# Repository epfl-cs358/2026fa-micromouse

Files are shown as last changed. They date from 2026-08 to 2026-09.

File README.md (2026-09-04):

# Fall 2026 CS-358 Individual Project: a Micromouse 🐭

<!--<p align="center"><img src="https://github.com/user-attachments/assets/d70ca096-ef3c-48a5-9e2c-f239ba1cced6" width=700></p>-->

<!--<p align="center"><img src="https://github.com/user-attachments/assets/1fc31847-2d3d-4c5c-aa62-841a447577e7" width=600></p>-->



## Project overview

This semester project focuses on micromice which are small autonomous robotic "mice" designed to solve a maze as quickly as possible. As seen in [various videos](https://youtu.be/ZMQbHMgK2rw?si=J3iyXzNXOJgDFyq4), these robots can navigate and complete a maze in just a few seconds, demonstrating remarkable speed and precision.
<p align="center"><br><sub>Source: The Fastest Maze-Solving Competition On Earth<br><a>https://youtu.be/ZMQbHMgK2rw?si=60H5i8q6jv-QUGHG</a></sub></p>

Just like these spectacular micromice, we are going to build a little micromouse that uses sensors, motors, and a microcontroller. However, instead of solving mazes at a high speed, this project focuses on a different but equally interesting robotics challenge: **obstacle avoidance**, similar to a robotic vacuum cleaner. (Full maze solving is a bit involved for the individual project.)

You will build a small mobile robot capable of navigating an unknown environment, avoiding obstacles, much like a simplified Roomba. Below are some photos of the Micromouse you will build. (Note that those photos are from a more advanced version with three sensors and a Gyro)

<p float="left">
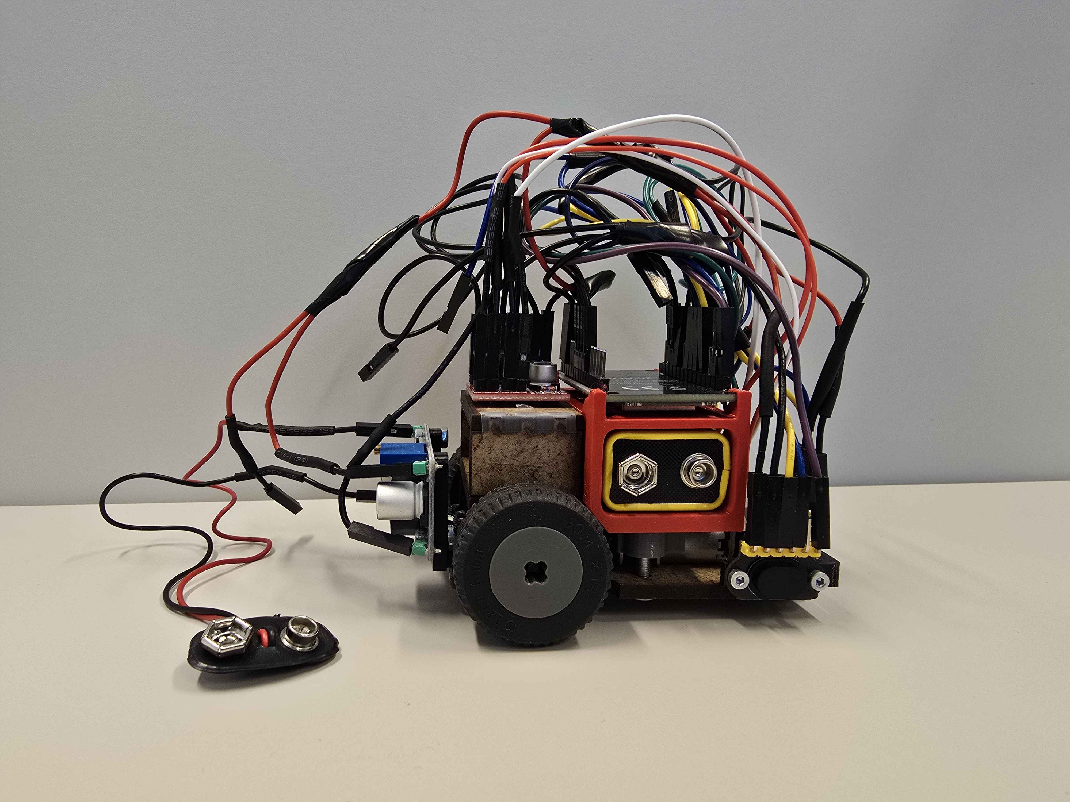
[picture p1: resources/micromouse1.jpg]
	
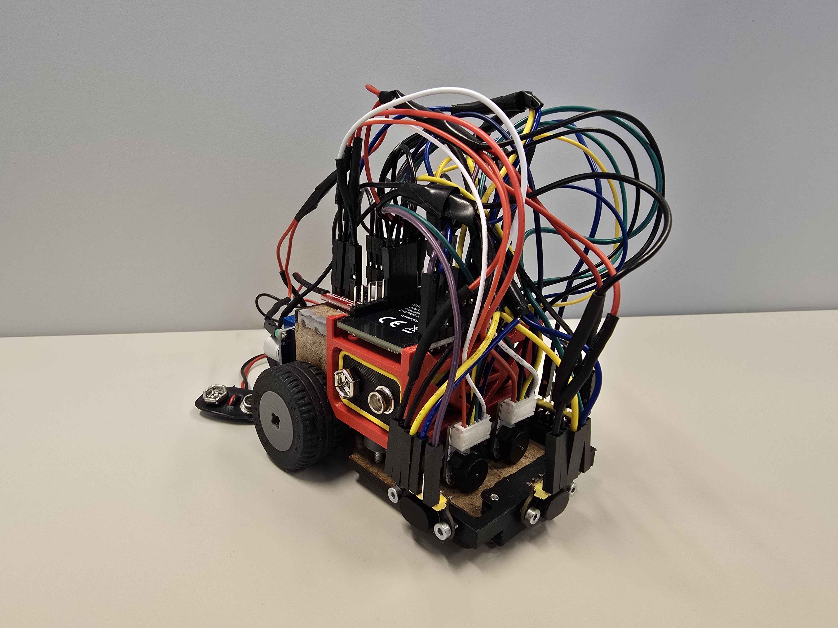
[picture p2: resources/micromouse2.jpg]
	
</p>  
<p float="left">
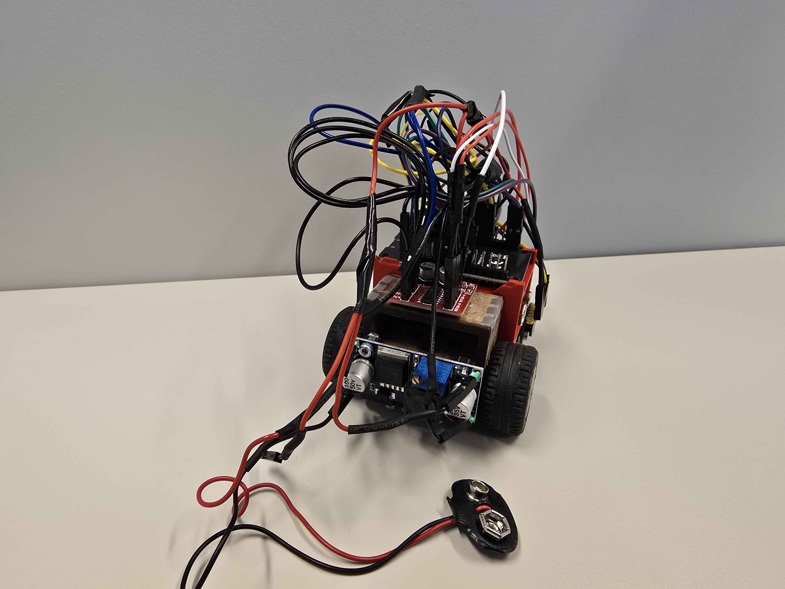
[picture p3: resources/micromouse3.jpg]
	
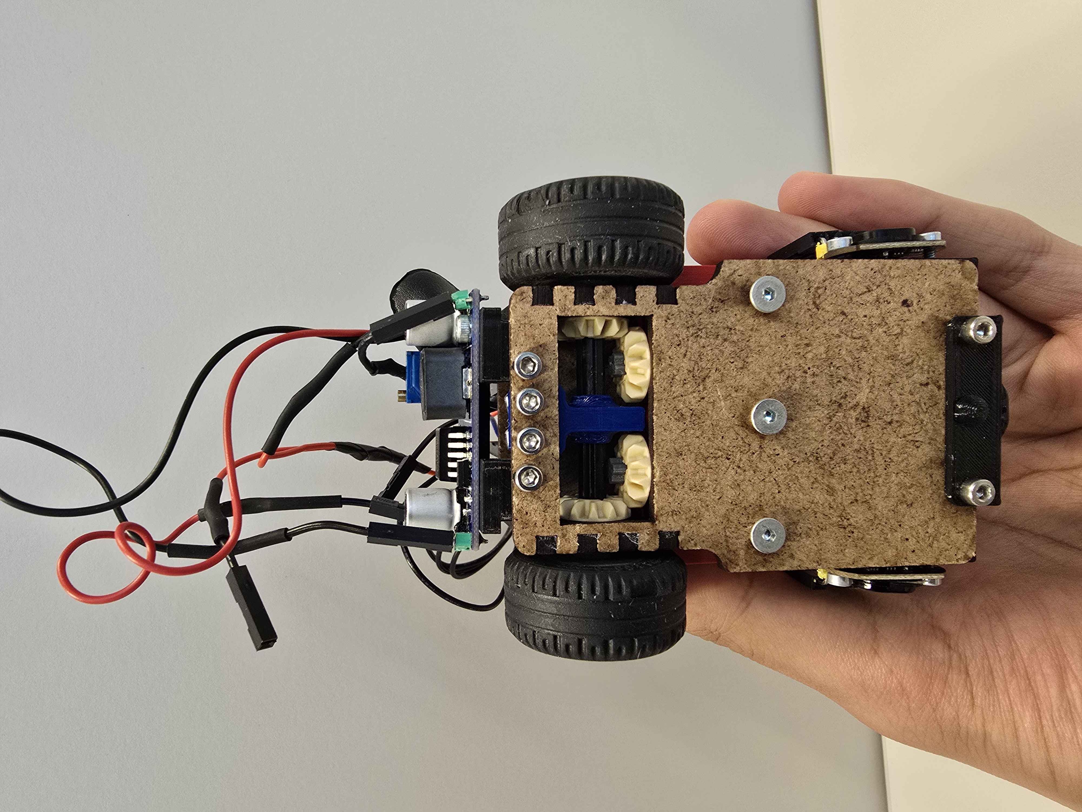
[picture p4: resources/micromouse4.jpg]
	
</p>  

The aim of this project is to get hands-on experience in a number of areas. We'll be learning how to assemble components following a circuit, soldering, 3D design, laser-cutting and programming micro-controllers.

⚠️ **An important note**: For this project, you can use either *Arduino IDE* or *PlatformIO*. Arduino IDE is a very basic IDE and also supports ESP32 development. However, please note that the time required to upload code to the ESP32 is high (on the order of one minute).

Another option is to use PlatformIO: a famous VSCode extension for programming microcontrollers, including ESP32s. Upload times are considerably faster with PlatformIO. In addition, familiarizing yourself with PlatformIO can be useful for other projects using ESP32s, Arduino and many other microcontrollers.

Whatever your choice, you'll find a tutorial for importing the project and installing the necessary libraries on Arduino IDE and PlatformIO in the [Software](#software) section

<!--⚠️ Please consider consulting the project proposal for more details about MinosMouse :memo:[Project proposal](https://github.com/epfl-cs358/2024fa-minosmouse/blob/cbe9dc045ea7b2e5f2d51d4c105a9bb93ee3844e/Proposal/MIT___MicroMouse.pdf):memo:-->

## Micromouse design

The micromouse is 95x58mm.

In order to achieve precise movement, the micromouse makes extensive use of control theory, more specifically PID systems. Thanks to this, the micromouse can correct itself in real time using its various sensors. 

### Hardware Overview

The micromouse consists of the following components:

- 2x N20 Motors 500RPM
- 1x Motor Driver MX1508
- 1x Time-Of-Flight sensors ToF400C-VL53L1X
- 1x Microcontroller ESP32 30pin
- 1x 9V battery
- 1x Buck converter LM2596
- 1x 9V battery connector
- 2x Lego axels 4L
- 2x Lego tires
- 4x Lego gears

⚠️ Check that no parts are missing before starting the project !

 Encoders keep track of how many steps each motor has taken. This is important because, unlike stepper motors, the brushed motors we're using for this project (N20 gear motors) are not exactly the same. In fact, these motors will always have a small difference in speed between them, and we need to compensate for this difference (however slight!) so that the micromouse can move straight forward / make precise movements. Thanks to the encoders, we can compensate for the difference in speed between the two motors by reading the number of steps each motor has taken, and trying to keep this number of steps almost equal.

## Tasks

### Overview

The goal of this semester is to work close to the hardware of the mouse, you'll have to build the mouse and code the interface with the sensors and motors. The expected behavior will be to drive up to an obstacle with a nice and straight tragectory, detect it, turn away and drive away. 

### 1 Hardware

 Build the mouse based on the instructions located further below in this document.

### 2 Design your 3D-printed wheels

To practice 3D design, you will design the wheels of the micromouse (not the tires).

The dimensions of the wheels are for you to choose, but beware: The behavior of the mouse depends heavily on these parameters!

Also, since we use lego shafts to attach the wheels to the gear box, you need to make sure, when designing the wheels, that the shaft fits in the wheel. For your information, here are the lego shaft dimensions:

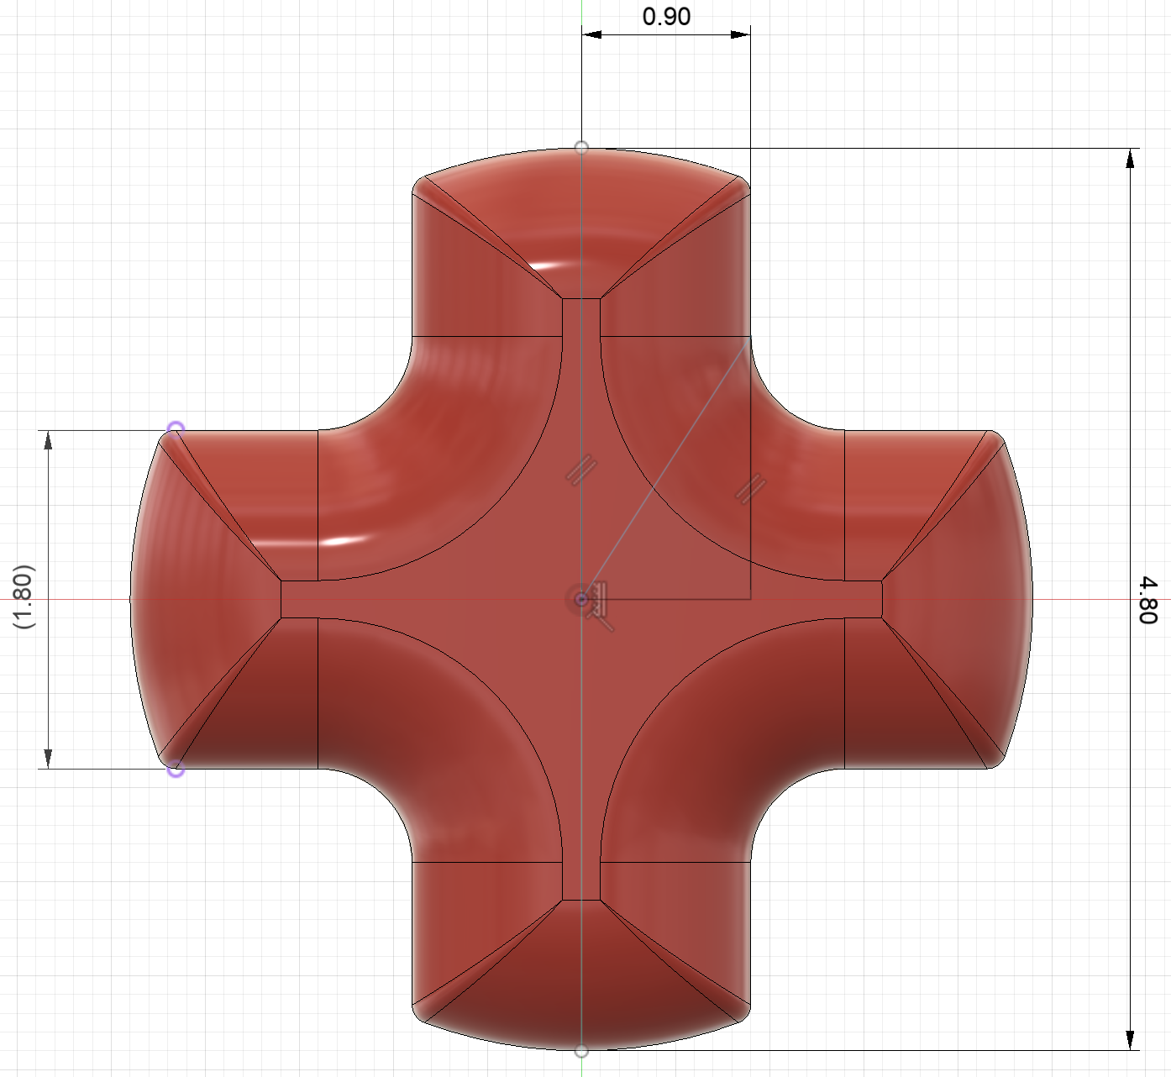
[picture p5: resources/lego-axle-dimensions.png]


For your reference, here is an example of a wheel that you may get inspired from. The tire is given to you and fits snuggly around a 17.7mm rim. The design given uses supports inside the rail that are a pain to remove, it's your job to find a better design if you want to avoid this issue :D

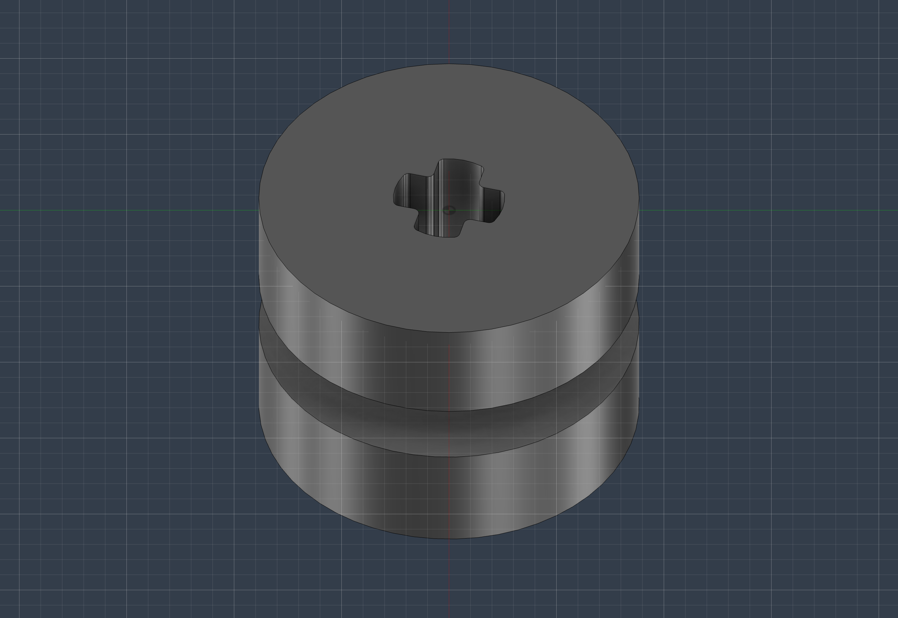
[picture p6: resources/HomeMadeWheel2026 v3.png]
  
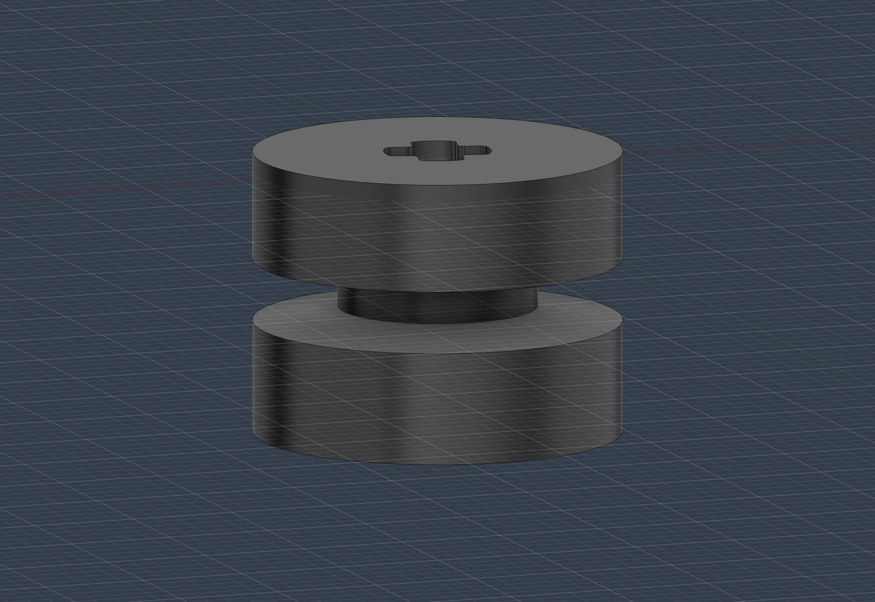
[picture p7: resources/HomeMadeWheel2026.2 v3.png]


This is the opportunity to make your product stand out! Fortunately this part is quite small and is therefore quite cheap and quick to manufacture, so don't be afraid to experiment!

### 3 Software Tasks

Your software tasks are divided into several categories:

#### Implement source files from provided interfaces

You will be given `.h` header files containing function signatures. Your task is to implement the corresponding `.cpp` files so that the functions exhibit the expected behavior.

- `encoders.h`  
  Functions related to encoder usage and measurements.

- `ToF.h`  
  Functions related to the front Time-of-Flight (ToF) sensor. You will need to calibrate your sensors to have accurate readings, this can be achieved with a simple linear regression.

- `motors.h`  
  Functions defining the API used to control the motors.  
  We have provided a few function signatures that we consider important, but this is not intended to be exhaustive. You are encouraged to extend the API with any additional functions you find useful. Make it your own.
  - Active braking

    Active braking is a technique used to stop a DC motor more quickly than simply cutting power.  
    With brushed DC motors, one common method is to short the motor terminals together. While the motor is still spinning, it acts like a generator and produces a voltage known as *back EMF* (electromotive force). By shorting the terminals, this generated current flows through the motor itself, creating a torque that opposes the rotation and rapidly slows the motor down.

    With brushed DC motors, this is commonly achieved by briefly shorting the motor terminals together (aka set both pins to High)

#### Design and implement algorithms independently

For these tasks, no file structure or function signatures will be provided. You are expected to design the software architecture and implementation yourself.

#### - Motor PID control

Implement a PID controller that adjusts the power delivered to each motor so both wheels rotate at the same speed. The objective is to improve the robot’s ability to drive in a straight line. 

A PID (*Proportional–Integral–Derivative*) controller is a feedback control algorithm commonly used in robotics and automation. It continuously measures the error between a target value and the current measured value, then adjusts the system output to minimize that error over time. You are expected to research how PID control works and tune your controller appropriately.

#### - Simple obstacle avoidance behavior

Implement an algorithm that:

1. Drives the robot forward in a straight line  
2. Detects an obstacle ahead  
3. Uses active braking and correction to stop approximately 5 cm from the wall  
4. Performs a ~140 degree turn in either direction to face away from the obstacle (you will not be graded on the accurracy of that turn)
5. Continues driving forward afterward

## Getting started: Making the micromouse

### Assembly

⚠️ At all times during the assembly process, refer to this document or to the provided `.step` file in order to avoid mistakes.

1. First things first, you need to laser-cut and 3D-print the parts of the micromouse. You can find the CAD of the parts to be laser-cut and 3D-printed in the project repository.

	You need to laser-cut the following parts:
    - 1x Base plate
    - 2x Side walls
	- 1x Top module plate

	You need to use **3mm** MDF: A sturdy enough width without being exceedingly heavy.

	You also need to 3D-print the following parts:
    - 2x N20-to-LEGO adapters
   	- 1x Motor bracket
   	- 1x Sensors holder
	- 1x Battery holder
   	- 1x Shaft holder
   	- 1x Backplate (Buck converter holder)

	⚠️ Most 3D parts were designed to require minimal to no supports. Be sure to disable them in PrusaSlicer when not necessary and mind the orientation of the parts when scheduling a print.

	### Useful PrusaSlicer Extras
  
	⚠️ If you want to specify which side of your part you want supported you can do that by using the **brush** tool. 
	

	⚠️Also, if you want the supports to be easily removable, you can use the **organic** supports option (although the sensor holder is the only piece that requires supports).
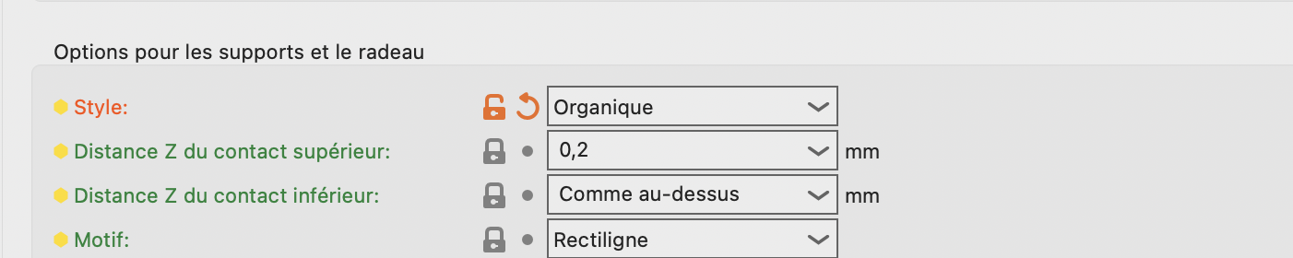
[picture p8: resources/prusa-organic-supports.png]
	

2. Once you have laser-cut parts, you can assemble them:

	⚠️ Be patient and careful when assembling MDF parts as they are fragile

	1. Put the shaft holder in the middle of the gearbox and scew it to the base plate.
	2. Wedge the top module plate on top of the two side plates.
	3. Wedge the aforementioned assembly into the base plate, you should feel some resistance.

💭 You should use **wood glue** to make everything secure but you will not be able to disassemble your mouse afterwards should you need to debug. Only do this if you are sure that you don't want to disassemble the parts.

3. Now, we install the motors on the micromouse:
    1. Put the N20-to-LEGO adapters on the motors
    2. Press the N20 Motors into the motor bracket. It should be a snug fit
	3. Insert nuts in the battery holder. Place the battery holder on top of the motor bracket and the Screw both of them to the chassi. Screws should be inserted from the bottom of the chassis.

	⚠️ Make sure the Lego adapter tips are properly aligned. The mouse would suffer from a lot of friction otherwise !
   
4. Mounting the gear box:
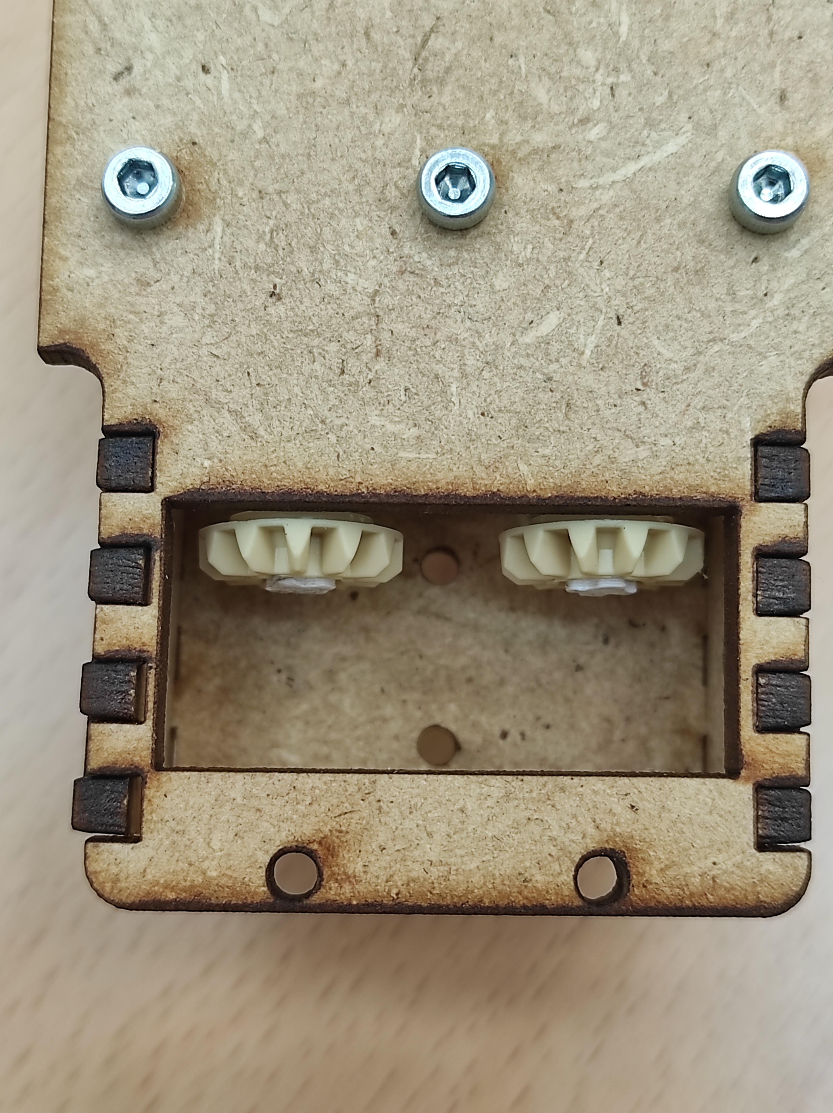
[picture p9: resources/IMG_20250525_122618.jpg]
	1. Install a gear on each of the N20-to-LEGO adapters. 
	2. Insert the lego shafts into the gearbox from the small hole in the gearbox walls. At the same time, add the other gear on the shaft and push it against the gearbox wall. The shafts should be maintained in place by the shaft holder which is in the middle of the gearbox.
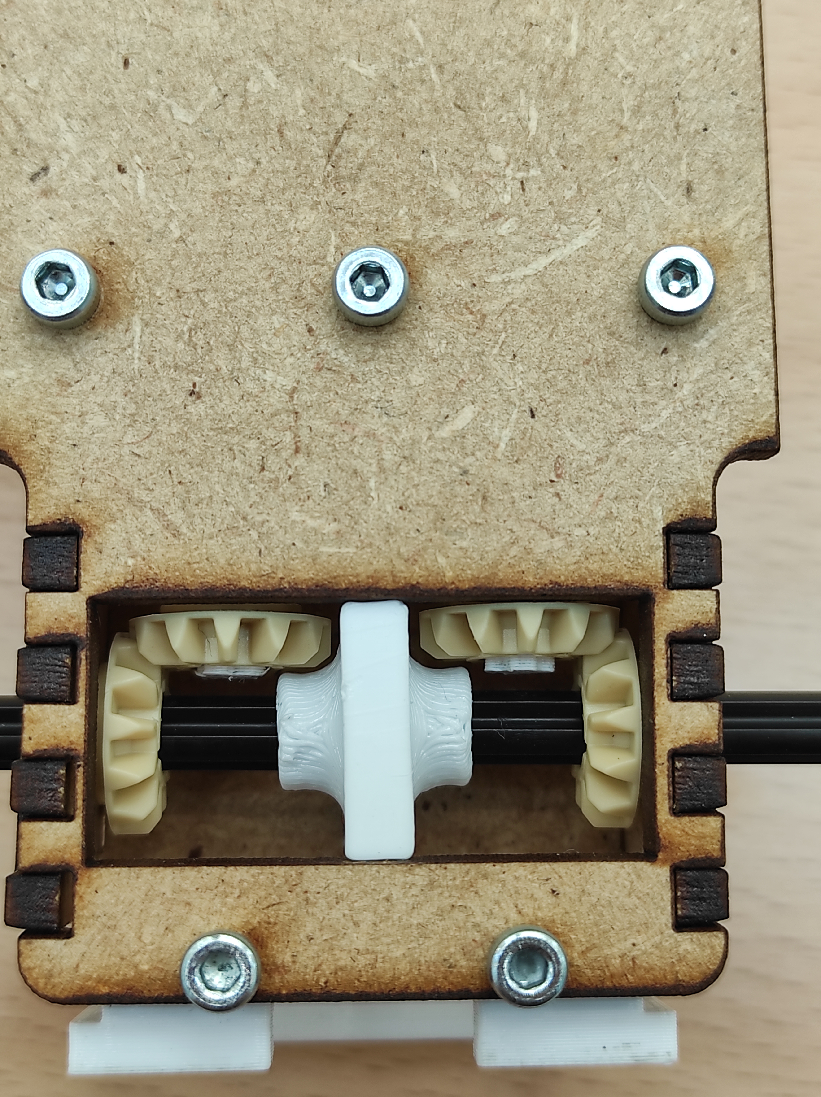
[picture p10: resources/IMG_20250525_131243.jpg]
	

5. Install the sensor holder on the front of the chassis. The sensor holder is designed to hold the 3 ToF sensors.

6. Finally, install the backplate on the back of the chassis by screwing it to the chassis. Same for the sensors holder: Attach it to the front of the chassis and screw it.

✅ After these steps, the basic mechanism of your mouse should be complete!

### Soldering
#### General Advice 
For this project, we recommend avoiding soldering wires directly to the boards. Instead, solder male header pins to the boards and create female cable assemblies to connect them.

When soldering male header pins to boards, make sure everything is stable and will not slip or move while you are heating the board and pins with the soldering iron. When soldering straight pins, you can use a breadboard to stabilize both the board and the pins (there is no need to push the pins too far into the breadboard). Make sure you adequately heat both the board and the pin before applying solder. The solder should not bead up, as that means the joint is too cold. Instead, it should flow smoothly around the metal ring and the pin, allowing you to add solder until you are satisfied with the amount.

We also recommend using appropriately sized solder wire for the task. For example, thinner solder wire makes it easier to control the amount of solder when working with the TOF sensor pins. The correct amount of solder should form an even, slightly convex “volcano” shape around the pin.

When soldering cable assemblies, make sure the stripped wires are twisted together securely. The wires should not pull apart easily once twisted together, the solder is intended primarily for electrical connectivity, not tensile strength. Try to find a good balance for the stripped wire length: if it is too long, it will require more solder and make it harder to achieve an even spread; if it is too short, twisting the wires together will be more difficult.

As with board soldering, make sure your setup is stable and that the wires are heated adequately before applying solder. Do not keep applying solder if it beads up, as this indicates the joint is not hot enough, remove the solder and continue heating.

A properly tinned soldering iron tip should look smooth, shiny, and evenly coated with a thin layer of solder. A dry, dark, or oxidized tip will not transfer heat effectively and will make soldering much more difficult. Regularly wipe the tip on the provided steel wool or brass wool cleaner and reapply a small amount of solder to keep it tinned between joints. If you have a stubborn black spot on the tip, you can use the acid paste to help remove the oxidation, then reapply solder to the tip and wipe it clean with the steel wool.
⚠️ Acid paste should be used sparingly as it can shorten the life span of the iron.

#### Schematics

The next step is to solder all the components together. This step needs to be done carefully as there is a lot of wires to solder in a small space.  

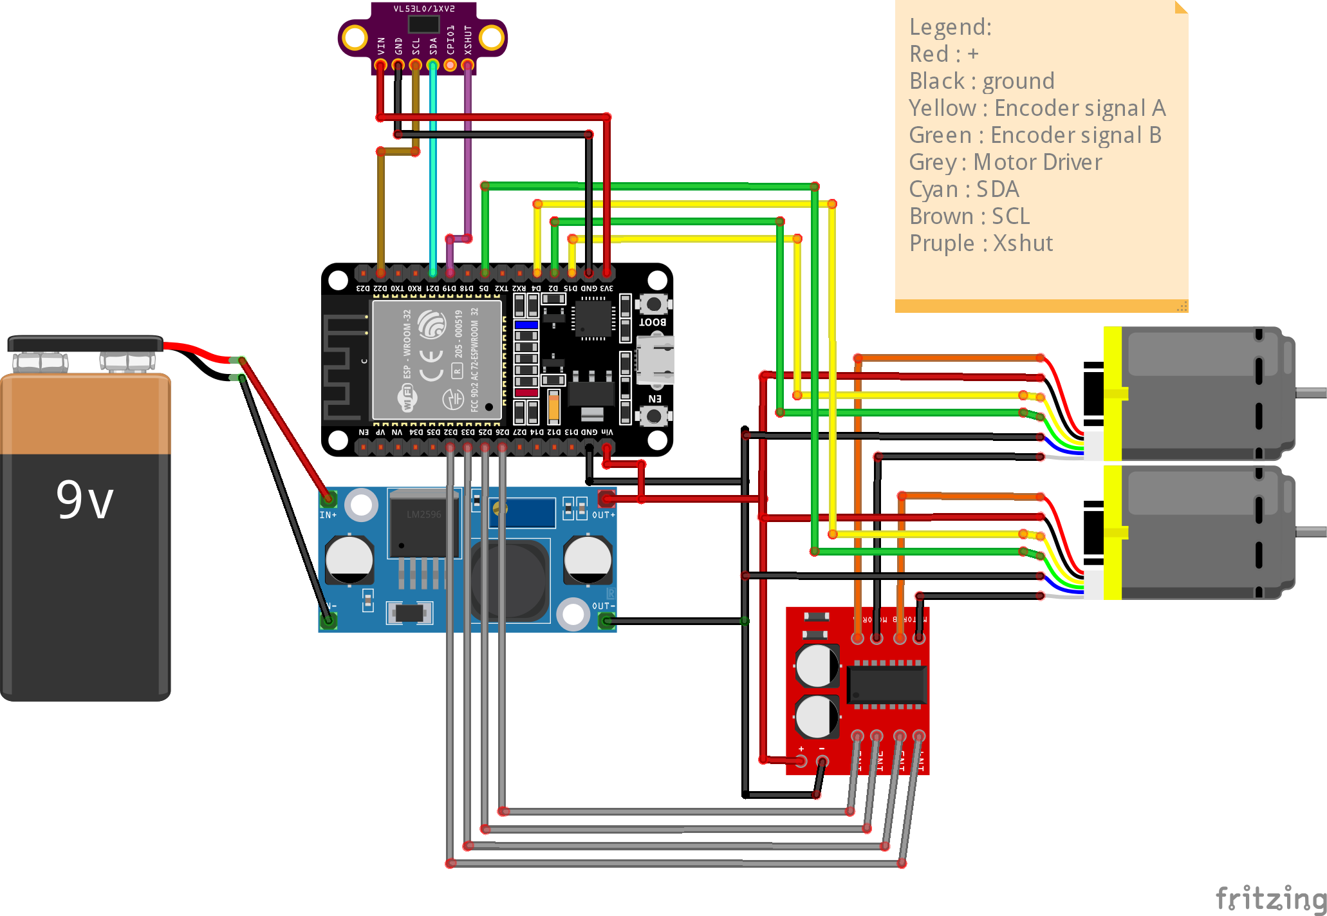
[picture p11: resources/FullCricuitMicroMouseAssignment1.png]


Keep in mind these important points:  
1. ⚠️ While this schematic accurately represents the soldering connections you should attempt to replicate we recognize it looks very cluttered as there are a lot of connections to make. For your convenience we linked a table with pinout assignments you can follow.

2. ‼️ Keep in mind that you cannot use every pin of the ESP32. Some pins have particular behavior. Please refer to the [following website](https://randomnerdtutorials.com/esp32-pinout-reference-gpios/) to know which pins you should prefer. As always we also include correct assignements you may want to use.

3. 💭 To have some clean soldering work, make sure to use heat shrink tubes or some electrical tape

4. 💭 For modularity, instead of directly soldering wires to the components, you can solder pin headers to your various components and use female wires.

5. 💭 Keep cables as short as they possibly need to be. This will have an enormous effect on the perceived cleanliness of the finished product.

#### *Power Connections*

##### Battery connector & Buck converter input 

Solder the $9V$ battery connector to the buck converter ```IN+``` and ```IN-```. 

‼️ Since we wish to output $5V$ to our system, we need to configure the buck converter to output $5V$. For that, use a multimeter (by putting the two multimeter probes on the ```OUT+``` and ```OUT-```) to measure the output voltage of the buck converter and adjust the potentiometer (Little golden screw) until you get $5V$.

💭 You might see very slow change in the voltage at first. That is normal! Keep adusting the potentiometer until voltage changes are higher.

##### Main power bus 

From the ```OUT+``` and ```OUT-``` of the buck converter, you will join all the power wires from every component together.

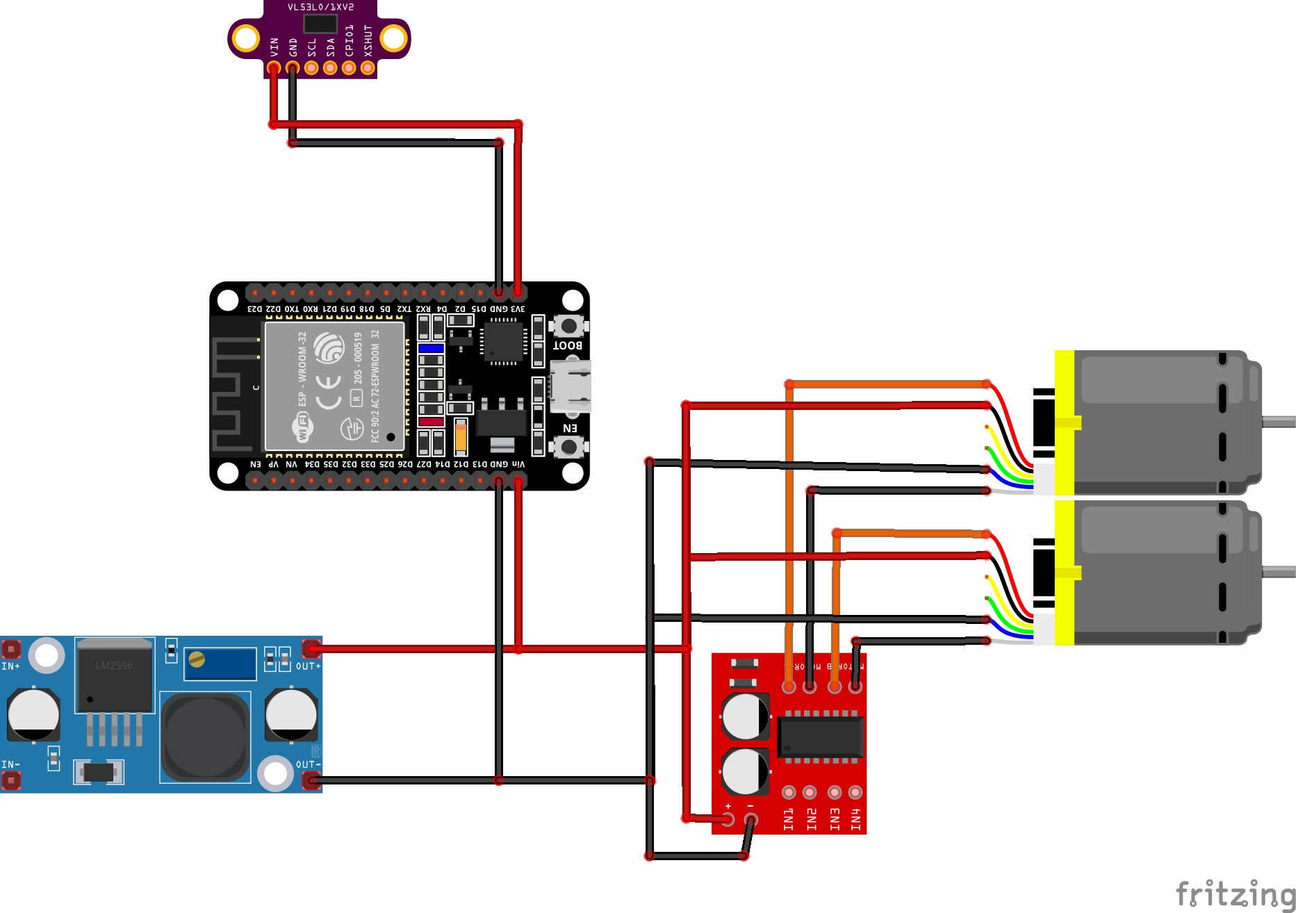
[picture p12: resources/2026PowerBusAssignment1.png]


<!-- 1. Solder the 2-PIN JST female connector to the 9V battery connector. -->

<!-- 1. From the 2-PIN JST female connector, solder two wires for power (one for the motors, and the rest for the switching regulator, to supply the rest of the components with $5V$) and one wire for ground. -->

1. Motor driver: Solder a wire for power and a wire for ground to the motor driver ```+``` and ```-``` pins.
2. Motors: 
- Left: Solder the motor ```+``` (Red wire) et ```-``` (White wire) to the motor driver (pins next to "Motor-A"). Solder a wire for encoder ```+``` (**Black** wire !) and for ```-``` (Blue wire).
- Right: Solder the motor ```+``` (Red wire) et ```-``` (White wire) to the motor driver (pins next to "Motor-B"). Solder a wire for encoder ```+``` (**Black** wire !) and ```-``` (Blue wire).

<p align="center"><br><sub>Source: <a>https://www.amazon.com/Torque-Electric-Encoder-Engine-Science/dp/B0CBR8Z617</a></sub></p>

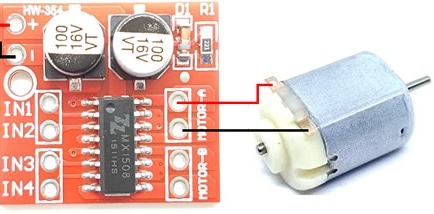
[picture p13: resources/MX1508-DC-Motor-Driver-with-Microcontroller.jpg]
<p align="center"><br><sub>Source: <a>https://components101.com/modules/mx1508-dc-motor-driver-pinout-features-datasheet</a></sub></p>

1. Sensors: Solder wires to ```VIN``` and ```GND``` pins of these components.
2. ESP32: Solder wire to ```V5``` and ```GND``` pins to supply power to the ESP32.
3. Join and solder all power wires together and all ground wires together (motor driver, sensors, encoders and ESP32) except for the motors, which are soldered to the motor driver. Once all the components to be supplied with $5V$ are connected together by two wire "bus" (one bus for power and one bus for ground), solder these two wire buses to the buck converter ```OUT+``` ($5V$ power bus) and ```OUT-``` (ground).

#### *Data Connections*

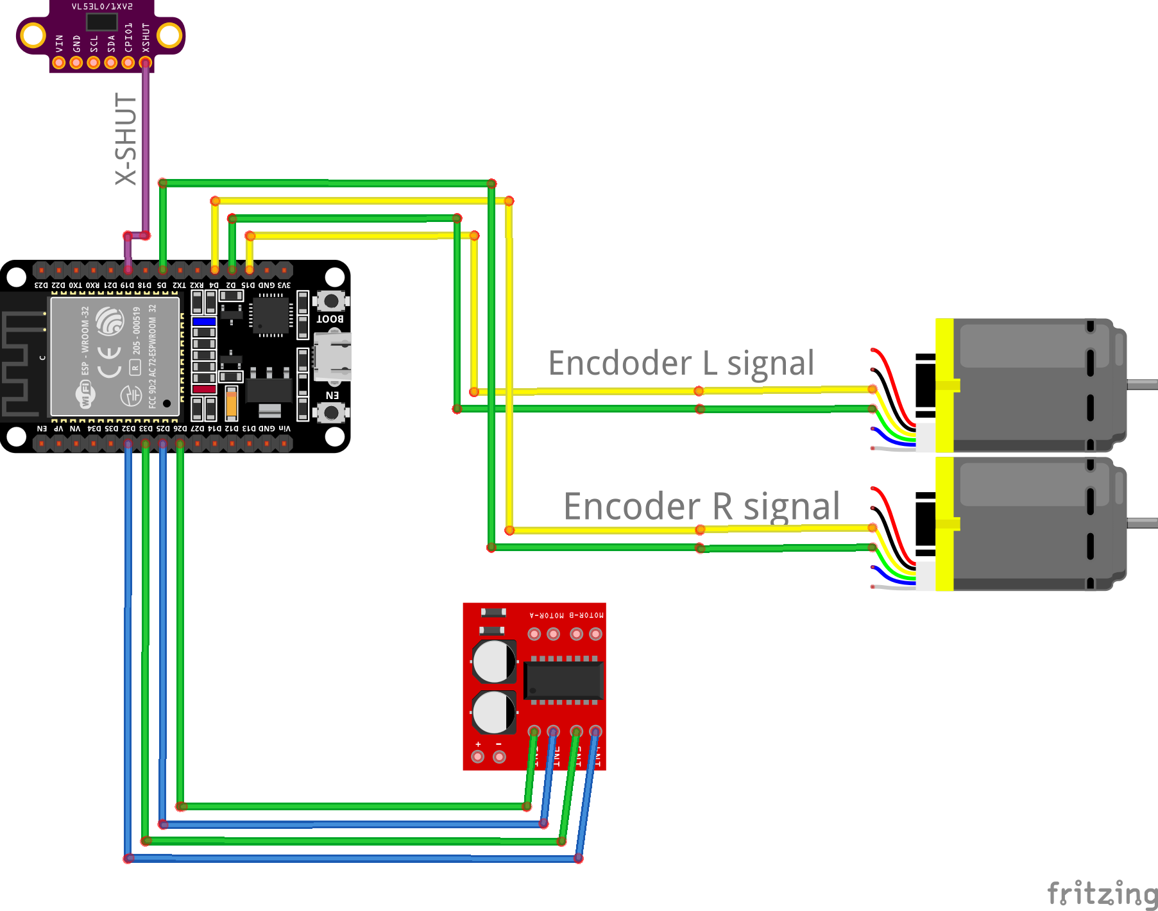
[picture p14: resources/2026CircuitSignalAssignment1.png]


- ##### Encoders
	1. Left motor encoder: Solder the **yellow** & the **green** wire of the encoder to pins of the ESP32.
	2. Same idea for the right motor encoder.

- ##### Motor Driver
	1. Left motor: Solder a wire between the **pin INT1** (Forward) of the motor driver and a pin of the ESP32. Same for the **pin INT2** (Backward), but with another pin of the ESP32.
	2. Same idea for the right motor.

	⚠️ Make sure that the pins you use are not "input only" pins (i.e GPIO 34, 35, 36, 39). 

- ##### X-SHUT
  	The X-SHUT pin is used to switch off the sensor. In case there we multiple sensors, we would need to switch them off one by one in order to redefine their addresses, because if they use the same addresses on the $I^2C$ bus, they'll send data to the same address and the data read by the ESP will be incorrect. (You don't have to worry about this aspect as there is only one sensor).

	1. Solder a wire between the **X-SHUT pin** of the sensor and a pin of the ESP32.

<br>

📝 In an ESP32 system, peripherals like ToF sensors communicate with the microcontroller on the same $I^2C$ bus (this is why in the schematic the SDA / SCL cables are combined), a multi-device serial protocol. Each device (sensor in our case) has a unique address, allowing the ESP32 to send commands and receive data.

- ##### Common $I^2C$ bus: 
  
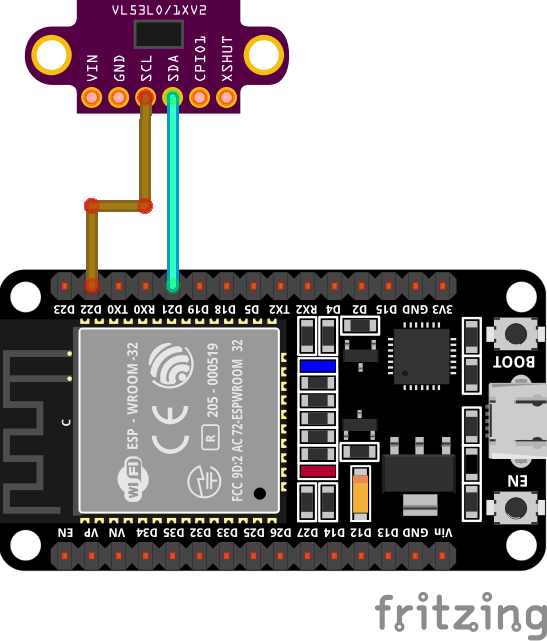
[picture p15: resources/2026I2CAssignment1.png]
	

💭 Often, the default $I^2C$ address is written on the rear face of the component.

<!-- After all these steps, you should have the following backbone:

<p align="center"><img src="https://github.com/user-attachments/assets/c56c94e3-f08b-4c96-8b28-4346304e5d3c" width=600 style="display: block; margin: 0 auto"></p> -->

### Mounting the electronical components

Once every electrical component has been soldered, we can mount them on the micromouse, in their appropriate place. Most of the screw to be used are M2.5 screws, except for the sensors, which are M2 screws.

And voilà! Your mouse is completed!

## Software

We need to setup the environment in which you will work on to be able to program and upload code to the micromouse.

If you want to use PlatformIO, follow the instructions below. If you want to use Arduino IDE, please refer to the [Arduino IDE](#arduino-ide) section.
### PlatformIO

1. Install VSCode on your computer. You can download it [here](https://code.visualstudio.com/).
2. In the extensions tab, search for PlatformIO and install it.
3. Download the [code](???) from the repository.
4. In VSCode, go to ```File``` > ```Open```. Look for the directory you just downloaded and open it. You should see a ```platformio.ini``` file in the root directory of the project.
5. Click on the PlatformIO icon in the left sidebar. Wait a bit for the project to load. Once it is loaded, you should see ```Build```, ```Upload``` and many other options under the ```Project Tasks``` section.
6. That's it ! You can now start coding in the ```src``` directory. The main file is ```main.cpp```. Each time you want to upload the code to the micromouse, click on the ```Build``` button in the PlatformIO sidebar, and then ```Upload```. If you want to read the serial monitor, click on the ```Upload and monitor``` button in the PlatformIO sidebar.

⚠️ If you have any issues when uploading the code, this may due to the fact that there is an "Upload" terminal still open. Close it (on the right of the VSCode window) and try again.
‼️ Make sure to disconnect the power pin of your ESP32 before uploading code. Not doing so sometimes leads to your laptop not recognizing the ESP.

### Arduino IDE
<!-- Follow [this tutorial](https://github.com/epfl-cs358/2024fa-minosmouse/blob/7f18ae96e44351af6db0aecf736b499a816c7f0b/Code/README_PIO.md) to install the necessary extension required for this project. -->
1. Install Arduino IDE on your computer. You can download it [here](https://www.arduino.cc/en/software).
2. Open Arduino IDE and go to ```Tools``` > ```Board``` > ```Boards Manager```.
3. In the search bar, type ```ESP32```.
4. Install the package made by "Espressif Systems".
5. Now, let's install the libraries we need for the sensors: 
	1. Go to ```Tools``` > ```Manage Libraries```.
	2. In the search bar, type ```VL53L1X``` & install the first one that appears.
6. You can now open the downloaded project in Arduino IDE. Go to ```File``` > ```Open``` and select the ```src``` directory of the project you just downloaded. You should see a ```main.cpp``` file in the root directory of the project, this is the file you will be working on.

‼️ If your computer doesn't recognize the ESP32, you may need to install a driver. You can find a tutorial here: [MacOS](https://randomnerdtutorials.com/install-esp32-esp8266-usb-drivers-cp210x-mac-os/) or [Windows](https://randomnerdtutorials.com/install-esp32-esp8266-usb-drivers-cp210x-windows/).

## Debugging - Testing the components the micromouse

To ensure that everything is working properly, and that your soldering work is correct, we want to test every components of the micromouse.  

For that, we provide you with a ```healthcheck.cpp``` file, which contains functions to check if everything is working properly: It will help you read the sensors, check that the motors work as expected and that the value read by the encoders are correct.

- Sensors: If you notice that the sensors doesn't work or you have some $I^2C$ related errors (appearing on the serial monitor), then first check in the pin assignment (this is probably due to some faulty X-SHUT pin assignment) in ```wiring.h```. If the pin assignment is correct, check your soldering work again. Also, if the values are not accurate, you may want to adjust the offset values in ```config.h```.
- Motors: If the motors don't go in the expected direction, then you should invert the pins of the motors in ```wiring.h```. If a motor doesn't work at all, then recheck the pins and/or your soldering work.
- Encoders: When moving forward the mouse should have positive values for the encoders, and negative values when moving backward. If the values are not correct, then check the pin assignment of the encoders and your soldering work. If the values doesn't get updated at all, then check your pin assignment and/or your soldering work.

If everything works as expected, then you have the necessary basis to start programming the micromouse !

## Appendix: Pinout

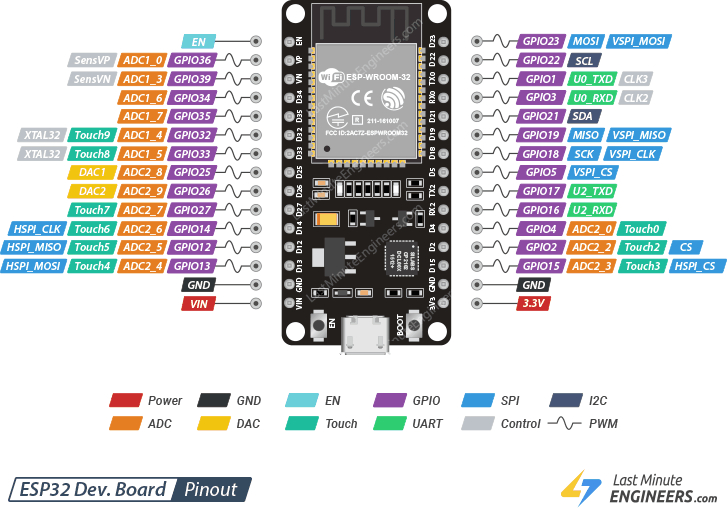
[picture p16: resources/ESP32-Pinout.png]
<p align="center"><br><sub>Source: <a>https://www.upesy.com/blogs/tutorials/esp32-pinout-reference-gpio-pins-ultimate-guide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</a></sub></p>

Here is an example of a pin assignment for the ESP32.

| Component | Pin Name | ESP32 Pin |
|---|---|---|
| Sensors 			 | I2C SDA | 21 |
| Sensors			 | I2C SCL | 22 |
| Left Motor | INT1 (Motor Driver) | 26 |
| Left Motor | INT2 (Motor Driver) | 25 |
| Right Motor | INT3 (Motor Driver) 	 | 33 |
| Right Motor | INT4 (Motor Driver) | 32 |
| Front Sensor | XSHUT_PIN_CENTER | 19 |
| Left Encoder | SIGNAL_FEEDBACK_YELLOW_LEFT | 15 |
| Left Encoder | SIGNAL_FEEDBACK_GREEN_LEFT  | 2 |
| Right Encoder | SIGNAL_FEEDBACK_YELLOW_RIGHT| 4 |
| Right Encoder | SIGNAL_FEEDBACK_GREEN_RIGHT | 5 |
| Power & Ground | 5V and GND | Vin and GND |
| Sensor power 		 | Vin and GND 				 | 3.3V and GND |

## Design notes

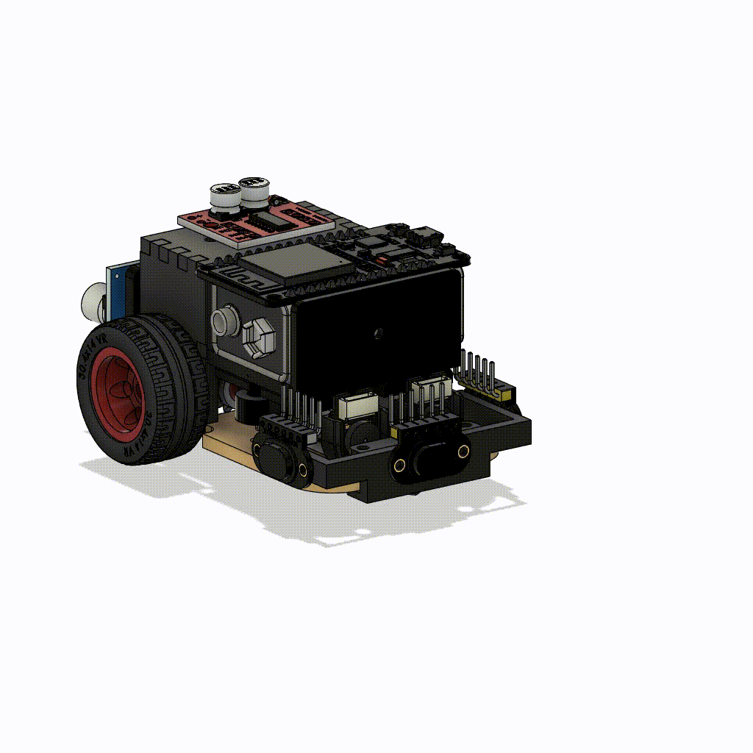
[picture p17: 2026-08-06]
resources/micromouse-animation.gif

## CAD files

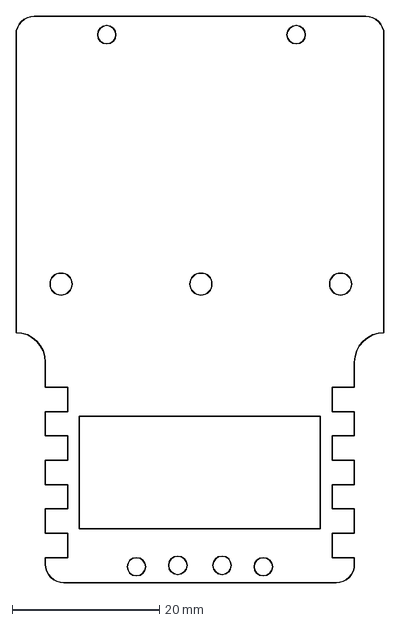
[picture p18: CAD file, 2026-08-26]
CAD/Baseplate 2026.dxf
50.0 x 77.0 mm

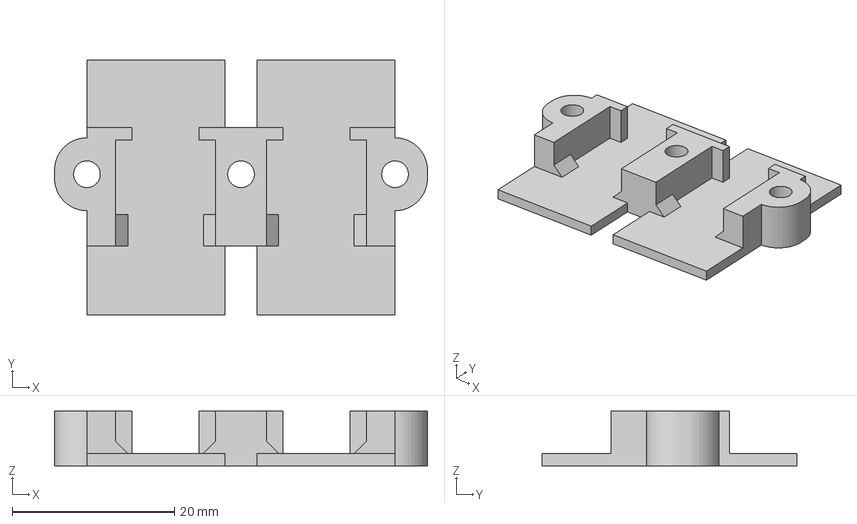
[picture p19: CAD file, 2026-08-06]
CAD/2026_Motor_bracket.3mf
46.0 x 31.4 x 6.75 mm

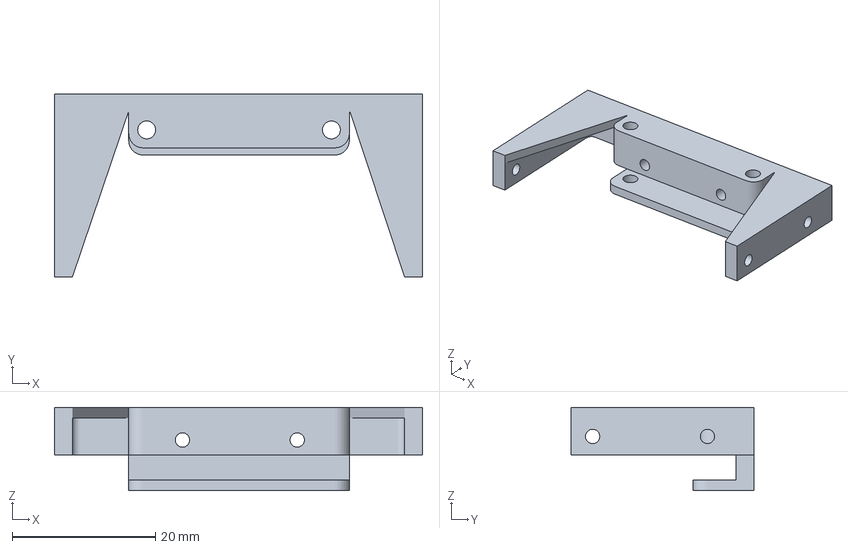
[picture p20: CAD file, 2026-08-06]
CAD/2026_Sensor_bracket.3mf
51.3 x 25.5 x 11.6 mm

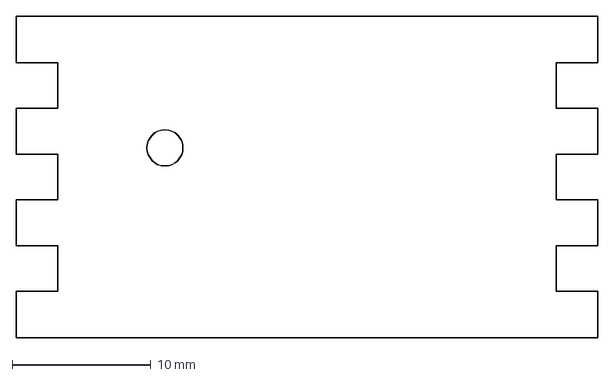
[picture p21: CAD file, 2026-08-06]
CAD/2026topPlate.dxf
42.0 x 23.2 mm

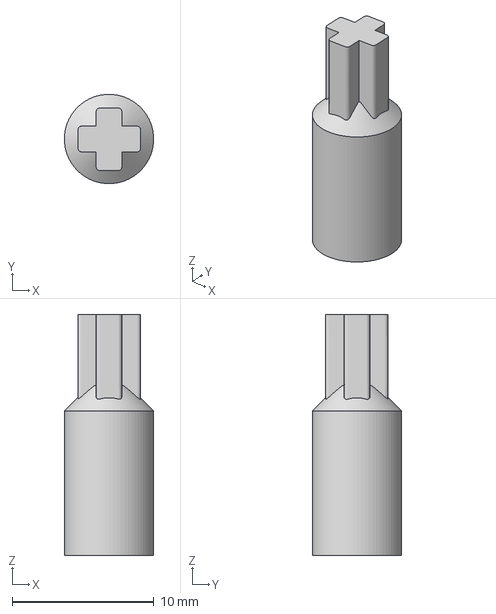
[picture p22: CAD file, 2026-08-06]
CAD/2026_N20_lego_adapter.3mf
6.30 x 6.30 x 17.0 mm

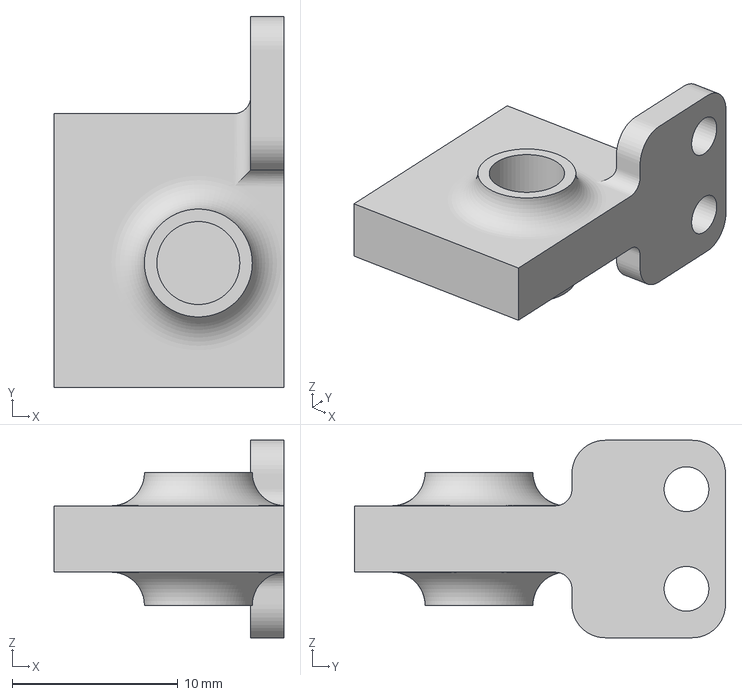
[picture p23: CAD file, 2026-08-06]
CAD/2026_axle_holder.3mf
13.8 x 22.4 x 11.9 mm

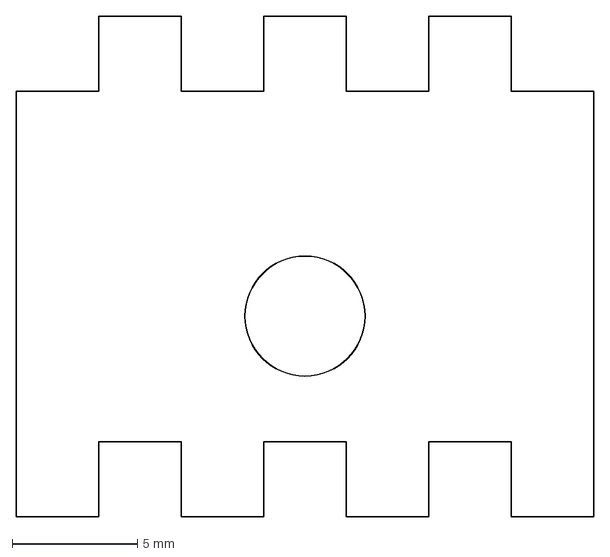
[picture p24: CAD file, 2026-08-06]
CAD/2026LowProfileSidePlate.dxf
23.1 x 20.0 mm

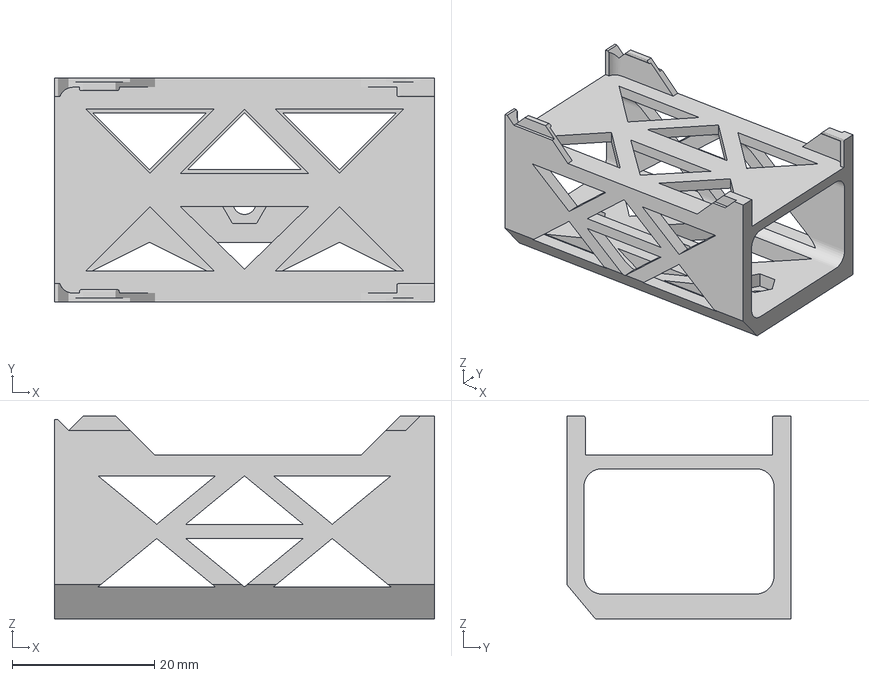
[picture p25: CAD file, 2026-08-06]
CAD/2026_BatteryHolder.3mf
53.4 x 31.5 x 28.5 mm

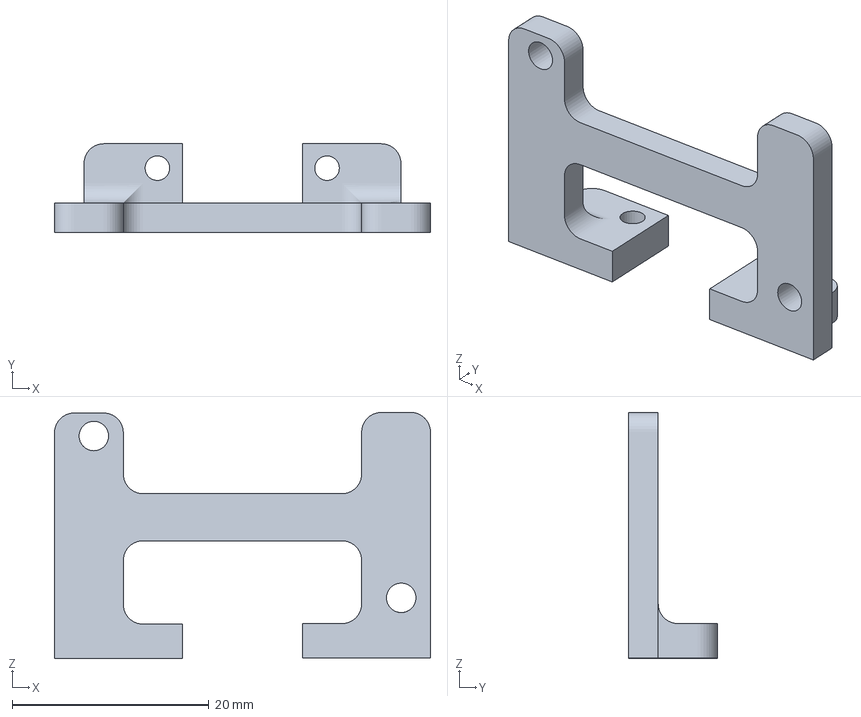
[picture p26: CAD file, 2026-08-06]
CAD/2026_Buck_converter_holder.3mf
38.2 x 9.00 x 25.0 mm

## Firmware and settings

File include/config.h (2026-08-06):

/**
 * @file config.h
 * @brief Robot geometry, motion, and maze configuration constants.
 *
 * Defines compile-time constants related to:
 *  - Physical robot geometry and kinematics
 *  - Motion control parameters (PWM limits and defaults)
 *  - Maze dimensions and start/goal configuration
 *  - Sensor thresholds and calibration values
 *  - Miscellaneous hardware-related constants
 *
 * These values are hardware- and build-specific and should be adjusted
 * to match the physical robot and competition setup.
 */
#pragma once
#include <Arduino.h>

/* ---------- geometry (measure yours!) ---------- */
constexpr float WHEEL_DIAMETER = 0;   // cm
constexpr int SPR = 0; // steps per revolution

/* ---------- motion constants ---------- */
constexpr int BASE_PWM = 0; // base PWM for speed-run
constexpr int TURN_PWM = 0; // base PWM for turns
constexpr int MIN_PWM = 0; // minimum PWM
constexpr int MAX_PWM = 0; // Maximum PWM 

// ---------- ToF sensor offsets (mm) ----------
// linear regression on sensors to calbrate them 
// CALIBRATE YOUR OWN!
constexpr float TOF_CENTER_OFFSET = 0.0f;
constexpr float TOF_CENTER_SLOPE = 0.0f;


/* ---------- misc ---------- */
const int LED_BUILTIN = 2;

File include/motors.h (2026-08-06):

/**
 * @file motors.h
 * @brief Dual DC motor driver abstraction for Micromouse.
 *
 * Provides high-level control of two DC motors, including forward/backward
 * motion, in-place turning, stopping, braking, and gyro-based yaw turns.
 */

#pragma once
#include <Arduino.h>

/**
 * @brief Hardware channel mapping for a single motor.
 *
 * Each motor uses two PWM pins and two hardware channels.
 */
struct MotorPins {
  int in1;  ///< PWM input pin 1
  int in2;  ///< PWM input pin 2
  int ch1;  ///< PWM channel 1
  int ch2;  ///< PWM channel 2
};

/**
 * @brief Configuration parameters for the motor driver.
 */
struct MotorConfig {
  MotorPins left;               ///< Left motor pin mapping
  MotorPins right;              ///< Right motor pin mapping
  uint16_t pwm_freq = 20000;    ///< PWM frequency (Hz)
  uint8_t  pwm_res  = 8;        ///< PWM resolution (bits)
  int16_t  max_pwm  = 255;      ///< Maximum PWM value
};

/**
 * @brief High-level dual motor controller.
 */
class Motors {
public:
  /**
   * @brief Initializes motor pins and PWM channels.
   *
   * @param cfg Motor configuration parameters.
   * @return true if initialization succeeded, false otherwise.
   */
  bool begin(const MotorConfig& cfg);

  /**
   * @brief Stops both motors (coast).
   */
  void stop();

  /**
   * @brief Brakes both motors (active short).
   */
  void brake();
};

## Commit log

2026-08-06 assignment 1 - handout
    [2026LowProfileSidePlate.dxf, 2026_BatteryHolder.3mf, 2026_Buck_converter_holder.3mf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]
2026-08-26 Fix Baseplate
    [Baseplate 2026.dxf]
2026-09-04 removed Gyro from healthcheck
